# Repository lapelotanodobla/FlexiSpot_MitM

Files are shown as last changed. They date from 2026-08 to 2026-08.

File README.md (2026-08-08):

# Flexispot Desk → Home Assistant (ESPHome MITM)

ESP32 man-in-the-middle between a Flexispot standing desk's control box and its keypad, built on ESPHome. The keypad keeps working exactly as stock; Home Assistant gets a live height sensor, up/down/stop, presets, and the ability to wake the desk on its own.

**Hardware this was built against:** HS01B-1 keypad, CB38M2A-1 control box (Flexispot E5B family), generic ESP32 devkit (WROOM), 2× female RJ45 breakouts, one 4-channel BSS138-style bidirectional level shifter, one 4.7 kΩ + one 10 kΩ resistor.

## Why this exists

The excellent prior art ([LoctekMotion_IoT](https://github.com/iMicknl/LoctekMotion_IoT), [standing-desk-interceptor](https://github.com/nv1t/standing-desk-interceptor), [loctek_IOT_box](https://github.com/Dude88/loctek_IOT_box), [ha-flexispot-standing-desk](https://github.com/grssmnn/ha-flexispot-standing-desk)) was mostly built for control boxes with **two RJ45 ports**: the keypad keeps its own port, the ESP plugs into the spare one, and plain TX/RX does the trick — no man-in-the-middle needed, and the keypad problem never arises. On a **single-port** box like this one, the ESP has to share the one line with the keypad, and the passthrough recipes adapted for that case tend to hit the same wall: the ESP can control the desk, but the keypad goes dead ([LoctekMotion_IoT#146](https://github.com/iMicknl/LoctekMotion_IoT/issues/146)). By passively sniffing a factory-wired desk first (phase 1) and only then going active (phase 2), this project found the causes:

1. **The bus is 5 V logic, not 3.3 V** (UART idles at 4.6 V). An ESP32 transmitting at 3.3 V sits at/below the switching threshold of the 5 V-logic keypad and controller — commands "work" by luck, the keypad goes deaf. Everything here goes through a level shifter.
2. **The protocol is strict poll/response.** The controller polls `9B:04:11` at ~31 Hz; the keypad answers every poll with its key state. Nobody free-runs.
3. **RJ45 pin 4 ("PIN 20") is driven by the keypad** as a wake line: high = session active, controller starts polling ~140 ms after the rising edge, sleeps ~10 s after inactivity (announced by a `9B:04:13` burst).
4. On this desk the documented TX/RX naming is swapped: **pin 6 carries keypad→controller, pin 5 carries controller→keypad**.

Full protocol write-ups: [`docs/superpowers/specs/2026-08-08-phase1-findings.md`](docs/superpowers/specs/2026-08-08-phase1-findings.md). Raw + annotated captures in [`captures/`](captures/), frame decoder in [`tools/decode.py`](tools/decode.py).

## Architecture (one line cut, one line split)

The ESP emulates *only* the keypad, toward the controller. The controller→keypad line is never touched, so display data reaches the keypad with factory electrics:

```
controller ──pin 5──┬────────────────────────────► keypad   (polls, display, keepalives
                    │                                        — physically untouched)
                    └──► ESP listens (tap)

keypad ──pin 6 (keypad side)──► ESP ──pin 6 (desk side)──► controller
         (ESP consumes real key frames,   (ESP answers every poll:
          or forwards unknown frames)      real keys, or HA-injected keys)

keypad ──pin 4 (keypad side)──► ESP sense ──pin 4 (desk side)──► controller
         (divider → GPIO21)      (GPIO22 → shifter: mirrors keypad wake,
                                  ORs in ESP's own wake for HA commands)
```

## Wiring

Both RJ45 breakouts sit back-to-back as a "coupler". Six of the eight lines are bridged straight through; **only lines 6 and 4 are cut**, and line 5 gets a tap.

Pin numbering note: hold the plug clip-down, contacts toward you, pin 1 on the left. **Verify with a meter before trusting any table**: pin 8 = +5 V, pin 7 = GND on the desk side.

| RJ45 line | Coupler | Connections |
|---|---|---|
| 1 (RES) | straight | — |
| 2 (SWIM) | straight | — |
| 3 (n/c) | straight | — |
| 4 (PIN 20) | **CUT** | keypad side → 4.7k → `GPIO21` node → 10k → GND · desk side ← shifter `HV4`, `LV4` ← `GPIO22` |
| 5 (controller→keypad UART) | straight + tap | tap → shifter `HV2`, `LV2` → `GPIO17` |
| 6 (keypad→controller UART) | **CUT** | keypad side → shifter `HV1`, `LV1` → `GPIO16` · desk side ← shifter `HV3`, `LV3` ← `GPIO23` |
| 7 (GND) | straight | ESP `GND`, shifter `GND` |
| 8 (+5 V) | straight | ESP `VIN`, shifter `HV` ref |

Shifter `LV` ref ← ESP `3V3`.

**Electrical notes**

- ESP32 pins are **not 5 V tolerant** — nothing from the bus may touch a GPIO without the shifter or the divider.
- The PIN 20 *sense* is a plain resistor divider (not a shifter channel) on purpose: shifter boards pull their HV side to 5 V, which would hold a sleeping desk awake.
- Power the ESP from desk 5 V (pin 8 → VIN). **Never desk 5 V and USB at the same time** — unplug the pin-8 lead before flashing over USB. OTA needs no cable.
- All ESP-side connections live on one header row of a 30-pin devkit (GPIO16/17/21/22/23 + 3V3 + GND) — single-side soldering, and none are boot-strapping pins.

## Repo layout

| Path | What |
|---|---|
| `desk-mitm.yaml` | The active MITM node (phase 2, current) |
| `desk-sniffer.yaml` | Passive sniffer node (phase 1, known-good fallback; wiring differs — see its spec) |
| `components/desk_mitm/` | ESPHome external component: `protocol.h` (pure logic) + glue |
| `tests/test_protocol.cpp` | Host-side unit tests; every vector is a captured frame |
| `captures/` | Raw + annotated sniff sessions |
| `tools/decode.py` | Turns a capture log into an annotated timeline |
| `docs/superpowers/specs/` | Design specs and protocol findings |
| `docs/superpowers/plans/` | Implementation plans |

## Usage

```sh
# secrets.yaml (not committed): wifi_ssid + wifi_password
esphome run desk-mitm.yaml                     # first flash over USB, then OTA
esphome logs desk-mitm.yaml                    # live logs over WiFi
c++ -std=c++17 -o build/test_protocol tests/test_protocol.cpp && ./build/test_protocol
```

Home Assistant entities (via native ESPHome API): a **cover named after the device** (position slider mapped over the calibrated travel range, open/close/stop) and a **`Target Height` number** (cm — type 110, desk goes to 110.0 ± 0.1), both driven by an on-device closed-loop engine (~500 ms wake from sleep, lands within one display quantum, physical keypad presses instantly override any automated move). Plus `Height` (cm, fetched automatically at boot via a wake pulse), buttons `Nudge Up`, `Nudge Down`, `Stop`, `Preset 1/2/3`, an `Emulation Mode` config switch, and diagnostics `Keypad Active` (PIN 20 sense), `Controller Awake` (disabled by default), `Refresh Height`. The node also serves a local web UI + REST API at its IP (`web_server`).

Calibrate once: jog to the physical bottom and top, read both heights, set the `min_height`/`max_height` substitutions. Closed-loop tunables (`coast_margin`, `deadband`, `settle_ms`, …) are component config — a heavier desk coasts further; that's the knob if landings need correction taps.

**ESP8266?** Workable: the keypad-side RX moves to software serial (only one full hardware UART), `logger: baud_rate: 0` frees UART0, and drop `web_server` for RAM. The component itself is platform-independent. An ESP32 remains the recommendation.

**Emulation Mode off** (default at boot) = echo mode: the ESP replays the real keypad's frames verbatim — zero protocol logic in the loop, useful as a first bring-up step and a permanent escape hatch. Injection requires the switch on.

## Protocol cheat sheet

Frames: `9B <len> <type> <payload…> <crc_hi> <crc_lo> 9D` · 9600 8N1 · `len` counts everything after itself incl. the `9D` · CRC-16/MODBUS over `[len, type, payload]`, high byte first.

| Frame | Who | Meaning |
|---|---|---|
| `9B:04:11:7C:C3:9D` | controller | key-state poll, ~31 Hz while awake |
| `9B:06:02:<k>:00:<crc>:9D` | keypad | reply to every poll; `<k>`: 01 up · 02 down · 04/08/10 presets · 20 M |
| `9B:07:12:<3 digits>:<crc>:9D` | controller | display (7-segment bytes, bit 7 = decimal point) |
| `9B:04:15:BF:C2:9D` | controller | keepalive, ~2 Hz |
| `9B:04:13:BD:42:9D` | controller | shutdown burst right before PIN 20 falls |

Presets are fire-and-forget (one ~150 ms key burst, controller completes the move). Manual up/down move only while the key streams.

## Safety / fail-safes

All key state clears on: poll silence >500 ms, CRC failure, shutdown burst, PIN 20 fall, reboot. Injections carry hard deadlines. Only single documented key masks can ever be emitted. Worst case: unplug the ESP and re-bridge coupler lines 6 and 4 → factory desk.

**⚠ Known hazard — ASR/RST reset state.** If the ESP loses power *during a preset (autonomous) move*, the controller loses position certainty and enters its reset state: display shows `ASr`/`RST`, only downward travel works, and power cycling does **not** clear it. Recovery takes a minute and is the standard Flexispot procedure: hold Down until the desk is fully lowered and `RST` shows (~10 s extra), release; on some units then hold Up (or Up+Down) until a normal height displays. Manual moves are unaffected — the controller stops cleanly when replies vanish. Stop semantics note: reverting to idle replies never cancels a preset move; the firmware's Stop button injects a ~60 ms key tap instead, which does (verified).

## Credits

Protocol groundwork by [iMicknl/LoctekMotion_IoT](https://github.com/iMicknl/LoctekMotion_IoT) and the projects linked above; this repo's contribution is the measured 5 V finding, the poll/response + PIN 20 semantics, and the keypad-emulation architecture built on them.

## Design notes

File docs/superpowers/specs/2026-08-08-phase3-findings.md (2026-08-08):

# Phase 3 Findings — Cover + Closed-Loop Move-to-Height

**Date:** 2026-08-08. Design: `2026-08-08-phase3-cover-design.md`. All results from live verification after calibration (travel 71.0–121.0 cm).

## Accuracy (live moves, default tunables)

| Target (cm) | Landed | Error | Notes |
|---|---|---|---|
| 79.5 | 79.5 | 0.0 | cold start: wake 492 ms → done in 4 s total |
| 85.0 | 85.1 | +0.1 | awake, up |
| 75.0 | 74.9 | −0.1 | awake, down |
| 71.0 | 71.1 | +0.1 | cover close → bottom rail |
| 83.5 | 83.6 | +0.1 | mid-range |
| 121.0 | 121.0 | 0.0 | full 37.5 cm climb (~18 s), top rail |

Max error = one display quantum (0.1 cm). **Zero fine-correction taps were needed in any move** — the default `coast_margin` 0.7 cm matches this desk's real coast almost exactly; COARSE + coast alone lands inside the 0.3 cm deadband. The FINE/tap stage exists as insurance (and is sim-verified), but on this hardware it never fires.

## Behaviors verified live

- **Physical override:** keypad Down pressed ~1.8 s into an automated 31 cm descent → `physical key 02 overrides move-to-height; aborting`, instant. Human always wins.
- **Cold-start moves:** target set while desk asleep → PIN 20 wake (~490 ms to polling), move runs, desk re-sleeps on its own.
- **Cover semantics:** position slider, open (→121.0), close (→71.1), all landing on the rails; position math verified against calibration (75.0 cm ↔ 0.246 pre-calibration, correct per formula).
- **Sleep cycles between moves** are handled transparently — back-to-back commands mix awake and cold-start paths without special-casing.

## Not exercised live (sim-verified only)

Stall abort (would require blocking the desk), move timeout, tap-limit exhaustion. All covered by `tests/test_protocol.cpp` against the SimDesk model.

## Tuning outcome

Ship defaults unchanged: `coast_margin` 0.7, `deadband` 0.3, `settle_ms` 1200, `move_timeout_ms` 30000, `stall_ms` 2000, `max_taps` 5. All exposed as component config for other desks (a heavier/lighter desk will coast differently — that's the knob to turn if landings start needing taps).

## Status

Phase 3 complete. The desk is a full HA citizen: cover with position, target-height box, presets, jogs, working stop, height telemetry, wake-on-demand, boot height fetch — all through a MITM that leaves the physical keypad factory-perfect.

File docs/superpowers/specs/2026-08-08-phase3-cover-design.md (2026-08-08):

# Phase 3 — Cover Entity + Closed-Loop Move-to-Height

**Date:** 2026-08-08
**Depends on:** `2026-08-08-phase2-mitm-design.md` (hardware unchanged), `2026-08-08-phase2-findings.md` (verified primitives: injection, wake, height telemetry, tap-cancels-move).

## Goal

A real Home Assistant `cover` entity (open/close/stop/position slider) and a `Target Height` (cm) number entity, both driven by one on-device closed-loop `move_to(cm)` engine. No hardware changes.

## Measured constants the design builds on (from captures/findings)

- Travel speed ≈ 2.2 cm/s during autonomous and held-key moves.
- A ~2-poll (≈60 ms) key tap moves ≈ 0.1 cm and cancels any autonomous move.
- Height frames stream continuously while moving; display resolution 0.1 cm.
- Desk coasts briefly after key release (sub-centimeter at manual speeds).
- Wake-from-asleep to first poll ≈ 500 ms via PIN 20 drive.

## MoveController (pure logic, `protocol.h`, host-tested)

State machine: `IDLE → (wake handled by glue) → COARSE → SETTLE → FINE → SETTLE → … → IDLE`.

- `move_to(target, now)`: validates target against `[min_height, max_height]`, computes direction, enters COARSE.
- **COARSE**: output the direction key continuously; when `|target − current| ≤ coast_margin` (default **0.7 cm**), release → SETTLE.
- **SETTLE**: output idle for `settle_ms` (default **1200 ms**) so coast finishes and the display catches up.
- **FINE**: if `|error| ≤ deadband` (default **0.3 cm**) → done (IDLE). Else emit one `tap_polls` (default 2) tap toward the target, → SETTLE. Max `max_taps` (default **5**) fine taps per move; exceeding it ends the move with a logged warning (good enough beats hunting).
- Tick interface: `uint8_t update(float current_height, uint32_t now_ms)` returns the key mask the glue should inject this instant; MoveController never touches hardware.

### Abort rules (all → IDLE, idle output, logged reason)

1. **Physical override**: glue reports any real-keypad key ≥ 1 frame → abort immediately. Human wins, always.
2. **Fail-safe events**: poll silence, `type 13` burst, PIN 20 fall, reboot (glue already clears key state; it also aborts the controller).
3. **Move timeout**: `move_timeout_ms` (default **30 s**) wall-clock cap.
4. **Stall**: height unchanged for `stall_ms` (default **2 s**) while COARSE is commanding motion — the desk's own anti-collision has tripped or something's wrong; do not fight it.

All constants are YAML substitutions with the defaults above.

## ESPHome entities

- **`cover` platform `desk_mitm`** (new `cover.py` + `DeskCover : cover::Cover`): traits position + stop. `position = (height − min_height) / (max_height − min_height)`, published on height change. `open` → `move_to(max_height)`, `close` → `move_to(min_height)`, `stop` → abort + existing stop-tap, `set_position(p)` → `move_to(min + p·(max−min))`. Device icon `mdi:desk`.
- **`number` platform `desk_mitm`** ("Target Height", cm, min/max from the same substitutions, step 0.1): `set` → `move_to(value)`. State reflects the last requested target.
- Existing sensor/buttons/switch unchanged. `move_to` while asleep rides the existing PIN 20 wake path (glue defers engine start until polling begins; existing 2 s wake timeout aborts the move if the controller never wakes).

## Calibration (bench step, part of the plan)

Jog to physical bottom and top with the keypad, read both heights in HA, set `min_height` / `max_height` substitutions. Until calibrated the YAML ships placeholder values 60.0 / 121.0 marked loudly as UNCALIBRATED.

## Testing

Host-side, extending `tests/test_protocol.cpp`: a `SimDesk` model (2.2 cm/s ramp while a key mask is applied, 0.4 cm coast after release, 0.1 cm quantization) driven against MoveController. Cases: long up move lands within deadband; long down move; early-release happens `coast_margin` before target; fine taps converge; tap cap respected; physical-override abort; stall abort; timeout abort; target clamping. The glue layer stays thin (entity plumbing + feeding `update()`), consistent with Phases 1–2.

## Non-goals

Preset programming from HA; speed control (hardware has none); ESP8266 build target (README gets a compatibility note only: 1 hW RX → software serial for keypad side, `logger baud 0`, drop `web_server`).

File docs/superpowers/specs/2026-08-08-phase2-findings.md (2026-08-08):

# Phase 2 Findings — Active MITM Verification

**Date:** 2026-08-08. Hardware per `2026-08-08-phase2-mitm-design.md` (single-cut keypad emulation, PIN 20 split). All results from live bench verification on the HS01B-1 / CB38M2A-1 desk.

## Verification ladder results

1. **Echo build — PASS.** Keypad fully functional through the ESP (display, jogs, presets). This confirms the core Phase 1 thesis: prior "keypad goes deaf" failures were 3.3 V transmit levels; at 5 V through the shifter the controller accepts ESP-relayed frames indistinguishably from the real keypad.
2. **Emulation build — PASS.** Keypad behavior indistinguishable from stock with the ESP synthesizing every poll reply from parsed key state. Height sensor tracks the display frames live.
3. **Injection — PASS.** HA/REST preset buttons execute full moves (verified to stored heights, e.g. preset 3 → exactly 75.0 cm); up/down jogs nudge as expected.
4. **ESP-initiated wake — PASS, deterministic.** Driving desk-side PIN 20 wakes the controller reliably: measured 493 ms, 508 ms, 524 ms, ~491 ms from drive to first poll across runs. **No polling was ever observed without the PIN 20 drive** — the UART-only wake hypothesis from older projects is dead on this hardware; the PIN 20 split is required for autonomous control.
5. **Abuse pass — one real discovery** (see hazard below). Not explicitly exercised: keypad unplug mid-manual-move (fail-safe designed: 500 ms poll-silence clears keys), OTA mid-move.

## Stop semantics (settled)

- Reverting to idle replies does **not** cancel a controller-autonomous (preset) move — the controller finishes on its own, exactly as the fire-and-forget model predicted.
- **Any brief up/down key press cancels an in-flight preset move** (verified physically and via injection).
- `stop()` therefore injects a ~60 ms (2-poll) up-tap, gated on "height changed within 500 ms" so Stop on an idle desk remains a true no-op. Verified: preset 1 launched from 77.2 cm, Stop pressed ≈1 s in, desk halted at 78.3 cm.

## Bugs found on hardware (both fixed)

1. **Watchdog time-underflow flap:** `loop()` captured `millis()` before draining UARTs while frame handlers stamped `last_poll_ms_` fresher; the unsigned subtraction wrapped and fired a false 500 ms poll timeout every cycle. Symptom: polling state flapping ~10×/s. Echo mode masked it (echo replies bypass key state). Fix: watchdog timestamp taken after the drain.
2. **Boot height fetch race:** the on-boot no-injection wake can race the controller's own sleep transition and produce nothing. Fix: bounded retry (3 attempts, 30 s apart, only until a height is ever decoded) plus a manual `Refresh Height` button.

## ⚠ Known hazard: ASR/RST reset state

**Cutting ESP power during a controller-autonomous (preset) move puts the desk into the ASR ("ASr"/"A5T"/"RST" on the display) reset state**: the controller loses position certainty when its keypad (the ESP) vanishes mid-move. In this state only downward travel works and power cycling does not clear it. Recovery (~1 minute, standard Flexispot procedure): hold Down until fully lowered, keep holding ~10 s until `RST` shows, release; if needed hold Up (or Up+Down on some units) until a normal height displays. Manual moves do not trigger this — the controller stops cleanly on reply silence. Documented in the README.

## Extra observations

- The keypad wakes itself when the controller starts transmitting on (intact) pin 5 — so HA-initiated moves light up the keypad display for free.
- Wake latency consistency (±20 ms around 500 ms) suggests a fixed controller boot sequence, useful as a health signal.
- Cold-wake injection sessions end with the same `type 13` shutdown burst + PIN 20 fall as keypad sessions; the controller makes no distinction between a real keypad and the emulation.

## Status

Phase 2 complete: keypad fully functional, HA control (height / jogs / presets / working Stop / wake-on-demand / boot height) verified end to end. Phase 3 candidates: closed-loop move-to-height, cover entity, hold-to-jog, preset programming from HA.

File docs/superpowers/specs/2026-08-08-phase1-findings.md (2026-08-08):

# Phase 1 Findings — HS01B-1 / CB38M2A-1 Protocol Sniff

**Source:** `captures/2026-08-08-session1.log` (annotated: `.md` sibling, decoder: `tools/decode.py`), captured with the passive Y-tap node (`desk-sniffer.yaml`). All frames CRC-verified 9600 8N1, format `9b <len> <type> <payload…> <crc16> 9d`.

## Physical-layer corrections vs the reference docs

- **5 V logic**, not 3.3 V (idle high 4.6 V). Any device transmitting to the controller or keypad at 3.3 V sits at/below the 5 V-logic V_IH — this is the most likely root cause of the "ESP works but keypad dies" failure mode in prior passthrough builds (iMicknl/LoctekMotion_IoT#146).
- **Direction naming is reversed** vs the iMicknl HS01B-1 table on this desk: RJ45 **pin 6 carries keypad→controller**, **pin 5 carries controller→keypad**.
- The keypad **tri-states its TX when asleep** (~1 V float); controller line idles high always.

## Protocol structure: poll/response, not free-running

Frame counts over the session: controller `type 11` = 2486, keypad `type 02` = 2486 — **exactly 1:1, with the keypad's reply ~6 ms after each poll**.

While awake (~31 Hz):

| Frame | Direction | Meaning |
|---|---|---|
| `9B:04:11:7C:C3:9D` | controller→keypad | Key-state poll, ~31 Hz |
| `9B:06:02:<k1>:<k2>:<crc>:9D` | keypad→controller | Key-state reply to every poll |
| `9B:07:12:07:<d2>:<d3>:<crc>:9D` | controller→keypad | Display update (7-segment encoding, bit7 = decimal point), sent on change + periodic refresh |
| `9B:04:15:BF:C2:9D` | controller→keypad | Keepalive, ~2 Hz while awake |
| `9B:04:13:BD:42:9D` | controller→keypad | Shutdown announcement — burst of ~8 in the ~100 ms before PIN 20 falls |

## (a) Keypad command frames — confirmed, full button map

The keypad answers every poll with `9B:06:02:<keys>:00:<crc>:9D`. `<keys>` is a bitmask; observed values match the LoctekMotion command table:

| Button | Payload | Observed |
|---|---|---|
| none | `00:00` | continuous idle |
| Up | `01:00` | tap = 4 frames (~100 ms), hold = continuous |
| Down | `02:00` | same pattern |
| Preset 1 | `04:00` | single ~5-frame burst, desk then moves autonomously |
| Preset 2 | `08:00` | same |
| Preset 3 | `10:00` | same |
| M | `20:00` | display switches to `S-` programming prompt for ~4 s, then reverts |

Key facts: a **preset tap is fire-and-forget** — the desk completes the whole move while the keypad streams `00:00`. Manual up/down moves only while the key code streams; release stops the desk.

## (b) PIN 20 — answered

- **The keypad drives PIN 20.** Rising edge comes first; controller UART starts polling ~140 ms later; first clean frame ~350 ms after the edge.
- Stays high while awake; drops after **~10 s of inactivity** (button presses and motion reset the timer).
- The controller announces the impending sleep with the `type 13` burst, *then* PIN 20 falls, then both transmitters die mid-stream (trailing garbage bytes `9B:FF`, partial frames are normal at power-down and must be discarded).
- Wake transients: the keypad's first ~2 bytes after the rising edge (`00`, `FE`) are garbage — ignore bytes for ~300 ms after the edge.

## (c) Frames absent from the reference docs

`type 11` (poll), `type 13` (shutdown), `type 15` (keepalive) are not in the LoctekMotion tables. Issue #146's mystery frame `9B:05:02:00:A1:60:9D` (len 05) did not appear here — likely a variant firmware's idle reply.

## (d) Phase 2 (active MITM) requirements

1. **Level shift everything** — 5 V toward desk and keypad. 3.3 V TX is not reliably heard.
2. **Split PIN 20**: sense the keypad side (divider→GPIO), drive the desk side (shifter channel). Mirror keypad→desk by default; OR-in ESP's own wake when injecting.
3. **To inject a command with the keypad asleep**: drive desk-side PIN 20 high, wait ≥350 ms for the controller to start polling, then answer polls with the command payload for ~4-5 polls (~150 ms), then stream `00:00` idle replies. Presets are fire-and-forget after that; the move completes on its own. Keep PIN 20 high at least until the move ends (height sensor goes quiet).
4. **The controller is the poll master.** A passthrough MITM must forward polls promptly; the observed poll→reply turnaround is ~6 ms, so per-byte forwarding latency well under that is required. Frame-level store-and-forward at ~1 ms/byte UART speed fits comfortably.
5. **Height telemetry is free**: decode `type 12` display frames — payload is frame bytes 3–5 (after `9B <len> 12`), 7-segment encoded, bit7 = decimal point; 3-digit values ≥100 drop the dot. Decoder validated against session 1: continuous cm readings 75.0–121.0 with no gaps (session presets: P1=121.0, P2≈77.2, P3=75.0). Non-numeric glyphs appear only in the M-mode `S-` prompt.
6. **Hygiene**: discard partial frames after `type 13`/PIN 20 fall; ignore first ~300 ms of keypad bytes after wake.

## Exit criteria

Questions (a) and (b) from the design spec are answered from captures — Phase 1 complete. Not yet captured: preset *programming* exchange (session step 11 skipped); can be added to a later session if Phase 2 needs it.

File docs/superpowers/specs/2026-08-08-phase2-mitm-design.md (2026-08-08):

# Phase 2 — Active MITM via Keypad Emulation (single-cut)

**Date:** 2026-08-08 (rev 2 after external review — see "Review outcomes" at bottom)
**Depends on:** `2026-08-08-desk-sniffer-design.md` (Phase 1 hardware), `2026-08-08-phase1-findings.md` (protocol ground truth).

## Goal

The ESP32 intercepts only the keypad→controller direction, keeps the keypad fully functional, and adds minimal HA control: height sensor + buttons (up, down, stop, preset 1/2/3), with deterministic ESP-initiated wake.

## Architecture: emulate the keypad only

**Controller→keypad (pin 5) stays physically intact** — display frames, polls, keepalives and shutdown reach the keypad with original electrics and timing; the ESP taps it read-only (as in Phase 1). Only **keypad→controller (pin 6) is cut**: the ESP receives the real keypad's replies on the keypad-side segment and is the sole talker on the desk-side segment.

- The ESP hears every `9B:04:11` poll on the pin-5 tap and answers on desk-side pin 6 immediately with `9B:06:02:<keys>:00:<crc>:9D` from local state.
- `<keys>` = injected command if an injection is active, **else** latest real-keypad key state. Injection *replaces* (never ORs with) physical keys; opposing/undocumented combinations are never emitted.
- The real keypad still hears polls directly (pin 5 intact) and replies on its own schedule; the ESP consumes those replies to update `real_keypad_keys`.
- Any keypad frame that is **not** `type 02` is forwarded to the controller verbatim (covers preset-programming and unknown exchanges).

**PIN 20 (pin 4) is also cut**: keypad-side segment keeps the existing 4.7k/10k divider → GPIO34 (sense); desk-side segment is driven at 5 V via shifter ch 4. Firmware mirrors keypad→desk and ORs in its own wake request when injecting. This makes ESP-initiated wake deterministic instead of hoping the controller wakes from UART frames alone. (The UART-only wake question can still be answered experimentally from logs, but nothing depends on it.)

### Fail-safe key-state rules

- All key state (injected and mirrored) **clears** on: parser/CRC error on either bus, no controller poll for 500 ms, `type 13` shutdown burst, PIN 20 fall, reboot, or OTA.
- Injections carry a hard deadline (~150 ms for command bursts) — expiry clears them regardless of poll arrival; a stuck injection cannot outlive its window.
- Ignore keypad bytes for 300 ms after keypad-side PIN 20 rises (wake transients); discard partial frames after shutdown.
- Reply exactly once per received poll — never on a self-generated schedule (log timestamps from Phase 1 are batched and unsuitable for deriving a clock; the poll itself is the clock).

### Injection semantics

- **Preset 1/2/3** (`04`/`08`/`10`): command payload in poll replies for ~150 ms (4–5 polls observed from the real keypad; duration-bounded, not count-exact), then idle. Move is fire-and-forget by the controller.
- **Up / Down** (`01`/`02`): stream for ~300 ms per HA button press (coarse jog; closed-loop control is Phase 3).
- **Stop**: clear injection immediately — verified to stop *manual* motion. Whether it cancels a preset move is unknown; tested on the bench in verification step 3 and the entity renamed/documented accordingly if not.
- If the controller is asleep (no polls), an injection first raises desk-side PIN 20, waits for polling to start (~350 ms observed keypad-wake latency; timeout 2 s), then proceeds. PIN 20 held until the move completes (height frames go quiet) plus 1 s.

## Hardware delta from Phase 1

Cut RJ45 lines **6 and 4** inside the coupler; lines 1, 2, 3, 5, 7, 8 stay straight through.

| Segment | Via | ESP pin |
|---|---|---|
| Keypad-side pin 6 (keypad TX) → ESP | shifter ch 1 (existing) | GPIO16 (uart_keypad RX-only) |
| Desk-side pin 5 tap (controller TX) → ESP | shifter ch 2 (existing) | GPIO17 (uart_desk RX) |
| ESP → desk-side pin 6 (controller RX) | shifter ch 3 (new) | GPIO26 (uart_desk TX) |
| ESP → desk-side pin 4 (PIN 20 drive) | shifter ch 4 (new) | GPIO27 (output) |
| Keypad-side pin 4 → ESP | 4.7k/10k divider (existing) | GPIO34 (sense) |

All four channels of the single BSS138 board are now used; no second board needed. BSS138 + 10k pullup rise time (~2–5 µs) is ~2% of a 104 µs bit at 9600 baud — adequate; verification step 1 confirms empirically before anything depends on it.

## Firmware structure

- `components/desk_mitm/` — ESPHome external component (C++): shared frame parser (`9B` → len → payload → CRC-16/MODBUS → `9D`), key-state model with the fail-safe rules above, injection queue, height decoder (7-segment, payload bytes 3–5, validated against session 1), PIN 20 mirror/wake logic.
- Entities: `height` sensor (cm), `keypad_active` (GPIO34), `controller_polling` (diagnostic), buttons up/down/stop/preset 1–3.
- `desk-mitm.yaml` — new node config (same device name/IP). `desk-sniffer.yaml` stays untouched as the known-good fallback build.
- **Echo mode** (boolean): ESP re-emits the real keypad's `type 02` replies verbatim instead of synthesizing from state — the minimal-logic first build and a permanent escape hatch.

## Verification ladder (each step gates the next)

1. **Echo build**: physical keypad fully functional through the ESP (buttons move desk, display live) → proves the 5 V TX path, the cut wiring, and PIN 20 mirroring with minimal firmware in the loop.
2. **Emulation build**: keypad still factory-perfect; height sensor live in HA while moving with the keypad; kill-switch checks (yank keypad mid-hold → desk stops within 500 ms via poll-timeout rule).
3. **Injection, keypad awake**: HA preset button moves desk; stop behavior during manual jog and during a preset move recorded.
4. **ESP wake, keypad asleep**: HA preset from cold — PIN 20 drive brings controller up, injection completes. Also log whether polling ever starts *without* the PIN 20 drive (settles the UART-only wake question for the record).
5. **Abuse pass**: reboot ESP mid-move, OTA mid-move, simultaneous HA + physical input (physical wins after injection window), sleep-boundary injections.

## Risks

- Controller may validate reply timing/content more strictly than observed → reply-on-poll from RAM, echo-mode fallback.
- Keypad may misbehave when its TX has no controller listening (it talks only to the ESP now) → it can't tell the difference electrically; RX-side unchanged.
- Worst case recovery: unplug ESP, re-bridge coupler lines 6 and 4 → factory desk (two jumpers, documented here).

## Non-goals (deferred to Phase 3)

Closed-loop move-to-height, cover/position entity, hold-to-jog from HA, preset programming from HA.

## Review outcomes (Codex second opinion, 2026-08-08)

Accepted: single-cut architecture (pin 5 intact); PIN 20 split now instead of the UART-wake experiment; fail-safe key-state clearing; injection replaces rather than ORs physical keys; duration-bounded injection; poll-as-clock (no schedule derived from batched log timestamps); stop-semantics caveat; height decoder byte-indexing bug fixed and re-validated (`tools/decode.py`, payload bytes 3–5).
Rejected: replacing BSS138 with a dedicated buffer (rise time is 2% of bit period at 9600; empirically gated in step 1); removing the wake observation entirely (kept as free logging, nothing depends on it).

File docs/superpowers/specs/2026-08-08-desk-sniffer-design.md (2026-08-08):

# Flexispot Desk — ESPHome Sniffer/MITM Design

**Date:** 2026-08-08
**Hardware:** Flexispot desk with HS01B-1 keypad / CB38M2A-1 control box, generic ESP32 devkit, 2× female RJ45 breakouts.
**Context:** Prior attempts (like [iMicknl/LoctekMotion_IoT#146](https://github.com/iMicknl/LoctekMotion_IoT/issues/146)) get ESP control of the desk working but the keypad goes dead, with only a repeating `9B:05:02:00:A1:60:9D` frame visible and no button-press frames. Root cause unknown; suspected to involve RJ45 pin 4 ("PIN 20", the screen-activation line). We start from scratch and capture ground truth before building control.

## Goals

1. **Phase 1 (this spec):** a purely passive tap that logs all traffic in both directions plus the PIN 20 line, while desk and keypad remain in a factory-original circuit.
2. Use those captures to answer: what does a real HS01B-1 keypad send when buttons are pressed, and how does PIN 20 behave?
3. **Phase 2 (later, informed by Phase 1):** active MITM passthrough with command injection.
4. **Phase 3 (later):** full HA integration (height sensor, presets, up/down) with a working keypad.

## Non-goals (Phase 1)

- No desk control from the ESP. No TX pins connected. No HA control entities.
- No decoding logic on the node itself — raw hex logging only; analysis happens on the captured logs.

## Reference protocol (from LoctekMotion_IoT docs)

- UART 9600 baud, 8N1.
- Frames: `9b <len> <type> <payload…> <crc16-lo> <crc16-hi> 9d`.
- Controller→keypad: height display frames. Keypad→controller: command frames (e.g. wake `9b 06 02 00 00 6c a1 9d`).
- Control box accepts commands only while the "screen is active"; PIN 20 HIGH for ~1 s activates it.
- HS01B-1 RJ45 pinout: 8=+5V, 7=GND, 6=desk-TX, 5=desk-RX (keypad-TX), 4=PIN 20, 3/2/1=NC/SWIM/RES.

## Topology: Y-tap (passive)

All 8 lines run straight through between the two RJ45 jacks (desk cable in one, keypad in the other — electrically a coupler). Three signal lines and power additionally branch to the ESP:

```
desk RJ45 ═══════════ 8 straight wires ═══════════ keypad RJ45
                │           │          │
              pin 6       pin 5      pin 4
                │           │          │
             GPIO16      GPIO17     GPIO34      (+ pin 8→VIN, pin 7→GND)
                └────── ESP32 only listens ──────┘
```

| RJ45 line | ESP pin | Role |
|---|---|---|
| 8 (+5V) | VIN | Powers ESP from desk |
| 7 (GND) | GND | Common ground |
| 6 (desk-TX) | GPIO16 (via shifter ch. 1) | UART1 RX — controller→keypad traffic |
| 5 (keypad-TX) | GPIO17 (via shifter ch. 2) | UART2 RX — keypad→controller traffic |
| 4 (PIN 20) | GPIO34 (via 4.7k/10k divider) | Digital input (input-only pin), edge logging |

**Measured levels (2026-08-08, keypad direct to desk, vs pin 7):**

| Line | Keypad asleep | Keypad active |
|---|---|---|
| 4 (PIN 20) | 0 V | 4.1 V |
| 5 (keypad-TX) | 1 V (undriven/float) | 3.7 V |
| 6 (desk-TX) | 4.6 V (UART idle high) | 3.5 V (avg while transmitting) |

Conclusion: **5 V logic**, and PIN 20 is at 4.1 V while the keypad is awake. This is also the leading hypothesis for why past passthrough builds killed the keypad: the ESP re-transmitted desk frames at 3.3 V, below reliable V_IH for 5 V logic, so the keypad never heard them (and 3.3 V on PIN 20 may likewise not register as "high").

**Level shifting (ESP32 GPIOs are not 5 V tolerant, and Phase 2 must transmit at 5 V):**

- **Pins 6 and 5 (both UARTs): 4-channel BSS138-style bidirectional shifter board** from the start — correct RX levels now, correct 5 V TX in Phase 2 with no rewiring. RJ45 pin 8 → HV ref, ESP 3V3 → LV ref, common GND. Channel 1: pin 6 ↔ GPIO16; channel 2: pin 5 ↔ GPIO17. Do not use TXS0108-type auto-direction chips (unreliable with bus pullups/long cables at these speeds).
- **Pin 4 (PIN 20): plain resistor divider** — 4.7k from line to GPIO34, 10k from GPIO34 to GND (5 V→3.4 V; V_IH ≈ 2.5 V, abs max 3.6 V). Deliberately *not* on the shifter in Phase 1: the board's 10k HV pull-ups could pull a passively-low PIN 20 up to 5 V and hold the desk awake, contaminating the capture. If Phase 2 needs to drive PIN 20, that gets a dedicated 5 V driver (spare shifter channel or transistor) informed by the captures.

## ESPHome node (`desk-sniffer.yaml`)

- Board: generic `esp32dev`. WiFi from existing `secrets.yaml`; device currently at 192.168.40.65, known to HA as "Flexispot Desk". Keep `api:` + `ota:` so HA connectivity and OTA updates work.
- Two RX-only `uart:` buses at 9600 8N1 with `debug:` enabled, `after: delimiter: 0x9D`, hex dump `sequence`, direction-labeled `DESK>` (GPIO16 bus) and `KEYPAD>` (GPIO17 bus).
- `binary_sensor` (GPIO platform) on GPIO34 for PIN 20, logging state changes; exposed to HA for convenience.
- Logger at `DEBUG` level over WiFi (`esphome logs`); USB serial only needed for the first flash.

## Verification plan

1. Flash over USB → node joins WiFi → `esphome logs` streams over the network.
2. Keypad sanity in Y-tap circuit: display shows height, buttons move desk. If not, debug wiring/crimps before anything else — the circuit is electrically original, so failure here is physical.
3. Capture a labeled session into a log file committed to this repo (`captures/`): idle baseline, each button press (up, down, presets 1–3, M), a full preset move, preset programming — noting PIN 20 edges throughout.
4. Analysis answers, explicitly written up: (a) does the keypad emit `9b 06 02 …` command frames, and which; (b) PIN 20 behavior at rest / on wake / during presses; (c) any frames not in the LoctekMotion docs.

Exit criterion for Phase 1: questions (a) and (b) answered from captures. That data drives the Phase 2 design (how the MITM must drive/relay PIN 20 so the keypad stays alive).

## Risks

- **Voltage:** measured 5 V logic; mitigated by the dividers above.
- **UART invert/idle level:** if a bus shows garbage, first suspects are swapped pins 5/6 or inverted logic (`invert: true` on the UART pin is the test).
- **GPIO34 has no internal pull:** if PIN 20 floats when idle, readings may bounce; acceptable for logging (we care about driven states), can add external pulldown if noisy.
- **Powering from desk during flashing:** never USB and desk 5 V simultaneously unless the devkit's diode handles it; unplug RJ45 power lead when flashing over USB.

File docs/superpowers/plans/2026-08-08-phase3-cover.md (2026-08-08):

# Phase 3 Cover + Move-to-Height Implementation Plan

> **For agentic workers:** REQUIRED SUB-SKILL: Use superpowers:subagent-driven-development (recommended) or superpowers:executing-plans to implement this plan task-by-task. Steps use checkbox (`- [ ]`) syntax for tracking.

**Goal:** HA `cover` entity (open/close/stop/position) and `Target Height` number, driven by a host-tested closed-loop `MoveController` in the existing `desk_mitm` component.

**Architecture:** Per `docs/superpowers/specs/2026-08-08-phase3-cover-design.md`. `MoveController` is pure logic in `protocol.h`, ticked by the glue loop; it outputs a key mask, never touches hardware. Cover/number are thin ESPHome platforms on the component. No hardware changes.

**Tech Stack:** Existing repo conventions — pure C++ TDD via `tests/test_protocol.cpp` + `c++ -std=c++17`, ESPHome external component platforms (`cover.py`, `number.py`).

**Key constants (from findings):** travel ≈2.2 cm/s, 2-poll tap ≈0.1 cm, coast ≈0.4 cm, display step 0.1 cm.

---

### Task 1: MoveController happy path (TDD with SimDesk)

**Files:**
- Modify: `components/desk_mitm/protocol.h`
- Modify: `tests/test_protocol.cpp`

- [ ] **Step 1: Add SimDesk + happy-path tests** (append to `tests/test_protocol.cpp`, call new tests from `main`)

```cpp
// Simulated desk: 2.2 cm/s while a key is held, 0.4 cm coast after release,
// display quantized to 0.1 cm. Matches measured constants in the findings docs.
struct SimDesk {
  float h;
  float coast_left{0};
  int dir{0};
  void step(uint8_t mask, uint32_t dt_ms) {
    const float v = 2.2f * dt_ms / 1000.0f;
    if (mask == 0x01) { h += v; dir = 1; coast_left = 0.4f; }
    else if (mask == 0x02) { h -= v; dir = -1; coast_left = 0.4f; }
    else if (coast_left > 0) {
      float c = v < coast_left ? v : coast_left;
      h += dir * c;
      coast_left -= c;
    }
  }
  float display() const { return roundf(h * 10) / 10; }
};

// Drive controller against sim until it goes idle or 60 simulated seconds pass.
static void run_sim(MoveController &mc, SimDesk &sim, uint32_t &now) {
  const uint32_t deadline = now + 60000;
  while (mc.active() && now < deadline) {
    uint8_t mask = mc.update(sim.display(), now);
    sim.step(mask, 10);
    now += 10;
  }
}

static void test_move_controller_happy() {
  MoveConfig cfg;  // defaults from the spec
  {  // long up move lands within deadband
    MoveController mc(cfg);
    SimDesk sim{75.0f};
    uint32_t now = 1000;
    assert(mc.move_to(110.0f, sim.display(), now));
    run_sim(mc, sim, now);
    assert(!mc.active());
    assert(mc.end_reason() == MoveEnd::DONE);
    assert(std::fabs(sim.display() - 110.0f) <= cfg.deadband + 0.001f);
  }
  {  // long down move
    MoveController mc(cfg);
    SimDesk sim{110.0f};
    uint32_t now = 1000;
    assert(mc.move_to(75.0f, sim.display(), now));
    run_sim(mc, sim, now);
    assert(mc.end_reason() == MoveEnd::DONE);
    assert(std::fabs(sim.display() - 75.0f) <= cfg.deadband + 0.001f);
  }
  {  // early release: key must drop out BEFORE the display reaches the target
    MoveController mc(cfg);
    SimDesk sim{80.0f};
    uint32_t now = 1000;
    mc.move_to(90.0f, sim.display(), now);
    float last_commanded_h = NAN;
    while (mc.active() && now < 61000) {
      uint8_t mask = mc.update(sim.display(), now);
      if (mask != 0) last_commanded_h = sim.display();
      sim.step(mask, 10);
      now += 10;
    }
    assert(mc.end_reason() == MoveEnd::DONE);
    assert(last_commanded_h < 90.0f);  // released below target, coast covered the rest
  }
  {  // target outside range is clamped to the rail
    MoveConfig c2;
    c2.min_height = 60.0f;
    c2.max_height = 121.0f;
    MoveController mc(c2);
    SimDesk sim{119.0f};
    uint32_t now = 1000;
    assert(mc.move_to(300.0f, sim.display(), now));
    run_sim(mc, sim, now);
    assert(std::fabs(sim.display() - 121.0f) <= c2.deadband + 0.001f);
  }
  {  // NaN target rejected outright
    MoveController mc(cfg);
    assert(!mc.move_to(NAN, 75.0f, 1000));
    assert(!mc.active());
  }
}
```

- [ ] **Step 2: Run to verify failure**

Run: `c++ -std=c++17 -o build/test_protocol tests/test_protocol.cpp && ./build/test_protocol`
Expected: compile error — `MoveConfig`/`MoveController`/`MoveEnd` not defined.

- [ ] **Step 3: Implement in `protocol.h`** (before the closing `}  // namespace desk_mitm`)

```cpp
struct MoveConfig {
  float min_height{60.0f}, max_height{121.0f};
  float coast_margin{0.7f}, deadband{0.3f};
  uint32_t settle_ms{1200}, move_timeout_ms{30000}, stall_ms{2000}, tap_ms{60};
  uint8_t max_taps{5};
};

enum class MoveEnd : uint8_t { NONE, DONE, TAP_LIMIT, TIMEOUT, STALL, ABORTED };

// Closed-loop move engine. Pure logic: tick update() with the latest decoded
// height; it returns the key mask to emit right now (0 = idle). Never touches
// hardware; the glue owns wake, injection and abort triggers.
class MoveController {
 public:
  explicit MoveController(const MoveConfig &cfg) : cfg_(cfg) {}
  void set_config(const MoveConfig &cfg) { cfg_ = cfg; }

  // Starts a move. Target is clamped to [min_height, max_height]; NaN rejected.
  // `current` may be NAN (height not yet known) — COARSE waits for frames.
  bool move_to(float target, float current, uint32_t now) {
    if (std::isnan(target)) return false;
    if (target < cfg_.min_height) target = cfg_.min_height;
    if (target > cfg_.max_height) target = cfg_.max_height;
    target_ = target;
    start_ms_ = now;
    last_h_ = current;
    last_h_change_ = now;
    taps_ = 0;
    end_ = MoveEnd::NONE;
    state_ = State::COARSE;
    return true;
  }

  void abort() {
    if (state_ != State::IDLE) end_ = MoveEnd::ABORTED;
    state_ = State::IDLE;
  }

  bool active() const { return state_ != State::IDLE; }
  MoveEnd end_reason() const { return end_; }
  float target() const { return target_; }
  // Direction of the current move: +1 up, -1 down, 0 idle. For cover operation state.
  int direction(float current) const {
    if (state_ == State::IDLE || std::isnan(current)) return 0;
    return target_ > current ? 1 : -1;
  }

  uint8_t update(float h, uint32_t now) {
    if (state_ == State::IDLE) return 0;
    if (now - start_ms_ > cfg_.move_timeout_ms) return end_with_(MoveEnd::TIMEOUT);
    switch (state_) {
      case State::COARSE: {
        if (std::isnan(h)) {
          // Height unknown (e.g. just woke): hold still, wait for frames.
          // The stall guard below uses last_h_change_, armed at move start.
          if (now - last_h_change_ > cfg_.stall_ms) return end_with_(MoveEnd::STALL);
          return 0;
        }
        if (std::isnan(last_h_) || h != last_h_) { last_h_ = h; last_h_change_ = now; }
        float err = target_ - h;
        if (std::fabs(err) <= cfg_.coast_margin) {
          state_ = State::SETTLE;
          settle_until_ = now + cfg_.settle_ms;
          return 0;
        }
        // Stall only matters while we are commanding motion and it isn't happening.
        if (now - last_h_change_ > cfg_.stall_ms) return end_with_(MoveEnd::STALL);
        return err > 0 ? 0x01 : 0x02;
      }
      case State::SETTLE:
        if (now < settle_until_) return 0;
        state_ = State::FINE;
        [[fallthrough]];
      case State::FINE: {
        if (std::isnan(h)) return end_with_(MoveEnd::STALL);
        float err = target_ - h;
        if (std::fabs(err) <= cfg_.deadband) return end_with_(MoveEnd::DONE);
        if (taps_ >= cfg_.max_taps) return end_with_(MoveEnd::TAP_LIMIT);
        taps_++;
        tap_key_ = err > 0 ? 0x01 : 0x02;
        tap_until_ = now + cfg_.tap_ms;
        state_ = State::TAP;
        return tap_key_;
      }
      case State::TAP:
        if (now < tap_until_) return tap_key_;
        state_ = State::SETTLE;
        settle_until_ = now + cfg_.settle_ms;
        return 0;
      case State::IDLE:
        break;
    }
    return 0;
  }

 private:
  uint8_t end_with_(MoveEnd e) {
    end_ = e;
    state_ = State::IDLE;
    return 0;
  }

  enum class State : uint8_t { IDLE, COARSE, SETTLE, FINE, TAP } state_{State::IDLE};
  MoveConfig cfg_;
  float target_{NAN}, last_h_{NAN};
  uint32_t start_ms_{0}, last_h_change_{0}, settle_until_{0}, tap_until_{0};
  uint8_t taps_{0}, tap_key_{0};
  MoveEnd end_{MoveEnd::NONE};
};
```

- [ ] **Step 4: Run tests** — `c++ -std=c++17 -o build/test_protocol tests/test_protocol.cpp && ./build/test_protocol` → `all tests passed`
- [ ] **Step 5: Commit** — `git add components tests && git commit -m "feat: MoveController closed-loop engine with simulated-desk tests"`

---

### Task 2: MoveController failure paths (TDD)

**Files:**
- Modify: `tests/test_protocol.cpp`

- [ ] **Step 1: Add failure-path tests** (call from `main`)

```cpp
static void test_move_controller_failures() {
  MoveConfig cfg;
  {  // abort mid-move: goes idle, outputs 0
    MoveController mc(cfg);
    SimDesk sim{75.0f};
    uint32_t now = 1000;
    mc.move_to(110.0f, sim.display(), now);
    (void) mc.update(sim.display(), now);
    mc.abort();
    assert(!mc.active());
    assert(mc.end_reason() == MoveEnd::ABORTED);
    assert(mc.update(sim.display(), now + 10) == 0);
  }
  {  // stall: height frozen while commanding motion
    MoveController mc(cfg);
    uint32_t now = 1000;
    mc.move_to(110.0f, 75.0f, now);
    while (mc.active() && now < 20000) {
      (void) mc.update(75.0f, now);  // desk never moves
      now += 10;
    }
    assert(mc.end_reason() == MoveEnd::STALL);
    assert(now - 1000 <= cfg.stall_ms + 100);
  }
  {  // timeout: motion keeps happening but never converges (stall never trips)
    MoveConfig slow = cfg;
    slow.stall_ms = 10000000;  // disable stall for this case
    MoveController mc(slow);
    uint32_t now = 1000;
    float h = 75.0f;
    bool flip = false;
    mc.move_to(110.0f, h, now);
    while (mc.active() && now < 60000) {
      (void) mc.update(h, now);
      h += flip ? 0.1f : -0.1f;  // jitter in place forever
      flip = !flip;
      now += 10;
    }
    assert(mc.end_reason() == MoveEnd::TIMEOUT);
  }
  {  // tap limit: deadband unreachably tight -> gives up after max_taps
    MoveConfig tight = cfg;
    tight.deadband = 0.001f;  // display quantizes to 0.1, can't ever satisfy
    MoveController mc(tight);
    SimDesk sim{75.0f};
    uint32_t now = 1000;
    mc.move_to(90.05f, sim.display(), now);
    run_sim(mc, sim, now);
    assert(mc.end_reason() == MoveEnd::TAP_LIMIT);
  }
  {  // NaN current at start: waits, then proceeds once height appears
    MoveController mc(cfg);
    uint32_t now = 1000;
    mc.move_to(80.0f, NAN, now);
    assert(mc.update(NAN, now + 100) == 0);  // holds still while blind
    SimDesk sim{75.0f};
    now += 500;  // height arrives 500ms in (post-wake)
    run_sim(mc, sim, now);
    assert(mc.end_reason() == MoveEnd::DONE);
  }
}
```

- [ ] **Step 2: Run** — Expected: all pass immediately if Task 1's implementation is correct; any failure here is a real bug — fix `MoveController`, not the test.
- [ ] **Step 3: Commit** — `git add tests && git commit -m "test: MoveController abort/stall/timeout/tap-limit/blind-start paths"`

---

### Task 3: Glue integration (wire MoveController into DeskMitm)

**Files:**
- Modify: `components/desk_mitm/desk_mitm.h`
- Modify: `components/desk_mitm/desk_mitm.cpp`
- Modify: `components/desk_mitm/__init__.py`

- [ ] **Step 1: `desk_mitm.h` additions**

Add includes/members/methods (forward-declare the entity classes):

```cpp
// at top, after existing includes
namespace desk_mitm {
class DeskCover;
class DeskNumber;
```

Inside `class DeskMitm`, public section:

```cpp
  void set_move_config(float min_h, float max_h, float coast, float deadband,
                       uint32_t settle_ms, uint32_t timeout_ms, uint32_t stall_ms,
                       uint8_t max_taps) {
    move_cfg_.min_height = min_h;
    move_cfg_.max_height = max_h;
    move_cfg_.coast_margin = coast;
    move_cfg_.deadband = deadband;
    move_cfg_.settle_ms = settle_ms;
    move_cfg_.move_timeout_ms = timeout_ms;
    move_cfg_.stall_ms = stall_ms;
    move_cfg_.max_taps = max_taps;
    mover_.set_config(move_cfg_);
  }
  void set_cover(DeskCover *c) { cover_ = c; }
  void set_target_number(DeskNumber *n) { target_number_ = n; }

  void move_to_height(float cm);
  void move_to_position(float pos) {
    move_to_height(move_cfg_.min_height + pos * (move_cfg_.max_height - move_cfg_.min_height));
  }
  float position_from_height_(float h) const {
    float p = (h - move_cfg_.min_height) / (move_cfg_.max_height - move_cfg_.min_height);
    return p < 0 ? 0 : (p > 1 ? 1 : p);
  }
```

Protected members:

```cpp
  MoveConfig move_cfg_;
  MoveController mover_{move_cfg_};
  uint8_t mover_mask_{0};
  float pending_target_{NAN};  // move deferred until controller wakes
  DeskCover *cover_{nullptr};
  DeskNumber *target_number_{nullptr};
  void publish_cover_state_();
```

- [ ] **Step 2: `desk_mitm.cpp` changes**

Add include at top: `#include "desk_cover.h"` and `#include "desk_number.h"` (created in Task 4; to keep this task compiling standalone, guard the two publish sites with `if (cover_ != nullptr)` — the pointers stay null until Task 4 wires them).

In `loop()`, after the UART drains and before the watchdog block:

```cpp
  // Tick the move engine once per loop; poll replies read mover_mask_.
  {
    const uint32_t t = millis();
    bool was_active = mover_.active();
    mover_mask_ = mover_.update(height_, t);
    if (was_active && !mover_.active()) {
      ESP_LOGI(TAG, "move ended: %d (height %.1f)", (int) mover_.end_reason(), height_);
      publish_cover_state_();
    }
  }
```

In `handle_desk_frame_` case `0x11`, next to the pending-injection start:

```cpp
      if (!std::isnan(pending_target_)) {  // wake-deferred move starts now
        mover_.move_to(pending_target_, height_, now);
        pending_target_ = NAN;
      }
```

In `handle_desk_frame_` case `0x12`, after `last_height_change_ms_ = now;` add `publish_cover_state_();`

In `handle_keypad_frame_`, type `0x02` branch — physical override:

```cpp
    if (f.payload[0] != 0 && mover_.active()) {
      ESP_LOGI(TAG, "physical key %02X overrides move-to-height; aborting", f.payload[0]);
      mover_.abort();
    }
```

In `reply_to_poll_`, emulation branch becomes:

```cpp
  uint8_t mask = mover_.active() ? mover_mask_ : keys_.current(now);
  auto reply = build_key_reply(mask);
  desk_->write_array(reply.data(), reply.size());
```

In `failsafe_clear_`: add `mover_.abort(); pending_target_ = NAN;`
In `stop()`: add `mover_.abort();` as the first line.
In `update_pin20_`: extend the hold condition — wake also held while `mover_.active() || !std::isnan(pending_target_)`.

New methods:

```cpp
void DeskMitm::move_to_height(float cm) {
  const uint32_t now = millis();
  if (!emulation_) {
    ESP_LOGW(TAG, "move_to_height ignored: emulation mode is off");
    return;
  }
  if (polling_) {
    if (mover_.move_to(cm, height_, now)) ESP_LOGI(TAG, "move_to %.1f cm", cm);
    return;
  }
  ESP_LOGI(TAG, "controller asleep; waking for move_to %.1f cm", cm);
  pending_target_ = cm;
  wake_request_ = true;
  wake_started_ms_ = now;
}

void DeskMitm::publish_cover_state_() { /* filled in Task 4; no-op until entities exist */
}
```

- [ ] **Step 3: `__init__.py` config options** — extend `CONFIG_SCHEMA` dict:

```python
        cv.Optional("min_height", default=60.0): cv.float_,
        cv.Optional("max_height", default=121.0): cv.float_,
        cv.Optional("coast_margin", default=0.7): cv.float_,
        cv.Optional("deadband", default=0.3): cv.float_,
        cv.Optional("settle_ms", default=1200): cv.positive_int,
        cv.Optional("move_timeout_ms", default=30000): cv.positive_int,
        cv.Optional("stall_ms", default=2000): cv.positive_int,
        cv.Optional("max_taps", default=5): cv.positive_int,
```

and in `to_code`:

```python
    cg.add(
        var.set_move_config(
            config["min_height"], config["max_height"], config["coast_margin"],
            config["deadband"], config["settle_ms"], config["move_timeout_ms"],
            config["stall_ms"], config["max_taps"],
        )
    )
```

- [ ] **Step 4: Gates** — host tests still pass; `esphome compile desk-mitm.yaml` succeeds (entities not in YAML yet).
- [ ] **Step 5: Commit** — `git add components && git commit -m "feat: wire MoveController into desk_mitm glue with wake, override and fail-safe aborts"`

---

### Task 4: Cover + number platforms, YAML, compile

**Files:**
- Create: `components/desk_mitm/desk_cover.h`
- Create: `components/desk_mitm/desk_number.h`
- Create: `components/desk_mitm/cover.py`
- Create: `components/desk_mitm/number.py`
- Modify: `components/desk_mitm/desk_mitm.cpp` (fill `publish_cover_state_`)
- Modify: `desk-mitm.yaml`

- [ ] **Step 1: `desk_cover.h`**

```cpp
#pragma once
#include "esphome/core/component.h"
#include "esphome/components/cover/cover.h"
#include "desk_mitm.h"

namespace desk_mitm {

class DeskCover : public esphome::cover::Cover, public esphome::Component {
 public:
  void set_parent(DeskMitm *p) { parent_ = p; }
  esphome::cover::CoverTraits get_traits() override {
    auto t = esphome::cover::CoverTraits();
    t.set_supports_position(true);
    t.set_supports_stop(true);
    return t;
  }

 protected:
  void control(const esphome::cover::CoverCall &call) override {
    if (call.get_stop()) parent_->stop();
    if (call.get_position().has_value()) parent_->move_to_position(*call.get_position());
  }
  DeskMitm *parent_{nullptr};
};

}  // namespace desk_mitm
```

- [ ] **Step 2: `desk_number.h`**

```cpp
#pragma once
#include "esphome/core/component.h"
#include "esphome/components/number/number.h"
#include "desk_mitm.h"

namespace desk_mitm {

class DeskNumber : public esphome::number::Number, public esphome::Component {
 public:
  void set_parent(DeskMitm *p) { parent_ = p; }

 protected:
  void control(float value) override {
    parent_->move_to_height(value);
    this->publish_state(value);
  }
  DeskMitm *parent_{nullptr};
};

}  // namespace desk_mitm
```

- [ ] **Step 3: fill `publish_cover_state_` in `desk_mitm.cpp`**

```cpp
void DeskMitm::publish_cover_state_() {
  if (cover_ == nullptr || std::isnan(height_)) return;
  float pos = position_from_height_(height_);
  int dir = mover_.active() ? mover_.direction(height_) : 0;
  auto op = dir > 0   ? esphome::cover::COVER_OPERATION_OPENING
            : dir < 0 ? esphome::cover::COVER_OPERATION_CLOSING
                      : esphome::cover::COVER_OPERATION_IDLE;
  if (pos != cover_->position || op != cover_->current_operation) {
    cover_->position = pos;
    cover_->current_operation = op;
    cover_->publish_state();
  }
}
```

- [ ] **Step 4: `cover.py`**

```python
import esphome.codegen as cg
import esphome.config_validation as cv
from esphome.components import cover
from . import DeskMitm, desk_mitm_ns

DEPENDENCIES = ["desk_mitm"]
CONF_DESK_MITM_ID = "desk_mitm_id"

DeskCover = desk_mitm_ns.class_("DeskCover", cover.Cover, cg.Component)

CONFIG_SCHEMA = cover.cover_schema(DeskCover).extend(
    {cv.GenerateID(CONF_DESK_MITM_ID): cv.use_id(DeskMitm)}
).extend(cv.COMPONENT_SCHEMA)

async def to_code(config):
    var = await cover.new_cover(config)
    await cg.register_component(var, config)
    parent = await cg.get_variable(config[CONF_DESK_MITM_ID])
    cg.add(var.set_parent(parent))
    cg.add(parent.set_cover(var))
```

- [ ] **Step 5: `number.py`**

```python
import esphome.codegen as cg
import esphome.config_validation as cv
from esphome.components import number
from esphome.const import CONF_MAX_VALUE, CONF_MIN_VALUE, CONF_STEP
from . import DeskMitm, desk_mitm_ns

DEPENDENCIES = ["desk_mitm"]
CONF_DESK_MITM_ID = "desk_mitm_id"

DeskNumber = desk_mitm_ns.class_("DeskNumber", number.Number, cg.Component)

CONFIG_SCHEMA = number.number_schema(DeskNumber).extend(
    {
        cv.GenerateID(CONF_DESK_MITM_ID): cv.use_id(DeskMitm),
        cv.Optional(CONF_MIN_VALUE, default=60.0): cv.float_,
        cv.Optional(CONF_MAX_VALUE, default=121.0): cv.float_,
        cv.Optional(CONF_STEP, default=0.1): cv.positive_float,
    }
).extend(cv.COMPONENT_SCHEMA)

async def to_code(config):
    var = await number.new_number(
        config,
        min_value=config[CONF_MIN_VALUE],
        max_value=config[CONF_MAX_VALUE],
        step=config[CONF_STEP],
    )
    await cg.register_component(var, config)
    parent = await cg.get_variable(config[CONF_DESK_MITM_ID])
    cg.add(var.set_parent(parent))
    cg.add(parent.set_target_number(var))
```

Note: `desk_mitm.cpp` includes `desk_cover.h`/`desk_number.h`; ESPHome compiles all files in the component dir, and the platform classes are header-only, so no extra build config is needed. If `cover.cover_schema(...)`/`number.number_schema(...)` don't exist in the installed ESPHome (API drift), check `.esphome` build cache of another project or the installed package source for the current names (`COVER_SCHEMA` etc.) and adapt — the C++ side is version-stable.

- [ ] **Step 6: `desk-mitm.yaml`** — add substitutions at the top and entities:

```yaml
substitutions:
  # UNCALIBRATED placeholders — set from the calibration step (Task 5)
  min_height: "60.0"
  max_height: "121.0"
```

Extend the `desk_mitm:` block:

```yaml
  min_height: ${min_height}
  max_height: ${max_height}
```

New top-level blocks:

```yaml
cover:
  - platform: desk_mitm
    name: "Desk"
    device_class: none
    icon: mdi:desk

number:
  - platform: desk_mitm
    name: "Target Height"
    unit_of_measurement: "cm"
    icon: mdi:human-male-height
    mode: box
    min_value: ${min_height}
    max_value: ${max_height}
    step: 0.1
```

- [ ] **Step 7: Gates** — host tests pass; `esphome config desk-mitm.yaml` valid; `esphome compile desk-mitm.yaml` succeeds.
- [ ] **Step 8: Commit** — `git add components desk-mitm.yaml && git commit -m "feat: desk cover and target-height number platforms"`

---

### Task 5: Calibration + live verification

**Files:**
- Modify: `desk-mitm.yaml` (real min/max)

- [ ] **Step 1: Flash** — `esphome run desk-mitm.yaml --device 192.168.40.65 --no-logs` → `OTA successful`.
- [ ] **Step 2: Calibrate** — user jogs (physical keypad) to the very bottom, notes height; then to the very top, notes height. Update the two substitutions, reflash. (Until then the entities work with placeholder rails — just don't trust position 0/1 extremes.)
- [ ] **Step 3: Live checks** (mix of REST/HA driving and user observation):
  - Number: set Target Height to a value ~10 cm away → desk lands within ±0.3 cm (read the sensor).
  - Cover: slider to 50% → desk goes to mid-range; open → top; close → bottom; stop mid-travel → halts.
  - Physical override: start a cover move, press a keypad key → move aborts instantly, keypad command wins.
  - Cold start: with desk asleep, set a target → wakes, moves, sleeps.
- [ ] **Step 4: Commit** — `git add desk-mitm.yaml && git commit -m "feat: calibrated desk travel range"`

---

### Task 6: Docs + close out

**Files:**
- Modify: `README.md`
- Create: `docs/superpowers/specs/2026-08-08-phase3-findings.md`

- [ ] **Step 1: README** — entity list gains the cover + number; add a short "ESP8266 compatibility" note (1 hardware RX → keypad side on software serial, `logger: baud_rate: 0`, drop `web_server`; ESP32 remains the recommendation); mention the closed-loop tunables (substitutions) in one sentence.
- [ ] **Step 2: Findings doc** — measured accuracy over several moves (target vs landed), any tuning changes to coast/deadband defaults, override/cold-start behavior, tap effectiveness.
- [ ] **Step 3: Commit + push** — `git add README.md docs && git commit -m "docs: phase 3 findings and README updates" && git push`

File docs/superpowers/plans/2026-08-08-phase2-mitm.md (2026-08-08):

# Phase 2 Active MITM Implementation Plan

> **For agentic workers:** REQUIRED SUB-SKILL: Use superpowers:subagent-driven-development (recommended) or superpowers:executing-plans to implement this plan task-by-task. Steps use checkbox (`- [ ]`) syntax for tracking.

**Goal:** ESP32 keypad-emulation MITM: keypad stays fully functional, HA gets height sensor + up/down/stop/preset buttons + deterministic wake.

**Architecture:** Per `docs/superpowers/specs/2026-08-08-phase2-mitm-design.md` (rev 2). Only RJ45 lines 6 (keypad→controller UART) and 4 (PIN 20) are cut; controller→keypad line 5 stays intact and tapped. Pure protocol logic lives in `components/desk_mitm/protocol.h`, unit-tested on the host against frames from `captures/2026-08-08-session1.log`; a thin ESPHome component wires it to UARTs/GPIOs.

**Tech Stack:** ESPHome external component (C++/esp-idf), host-side tests with plain `assert` via `c++ -std=c++17`, existing BSS138 shifter (4 ch) + 4.7k/10k divider.

**Protocol facts used throughout** (ground truth: `docs/superpowers/specs/2026-08-08-phase1-findings.md`):
- Frame: `9B <len> <type> <payload…> <crc_hi> <crc_lo> 9D`; `len` counts everything after itself including the trailing `9D`; CRC-16/MODBUS over `[len, type, payload…]`, transmitted **high byte first** (verified: `crc16([04,11]) = 0x7CC3` → wire bytes `7C C3`).
- Poll `9B:04:11:7C:C3:9D` (controller, ~31 Hz) → reply `9B:06:02:<keys>:00:<crc>:9D` (keypad). Keys: up=01 down=02 p1=04 p2=08 p3=10 M=20.
- Display `9B:07:12:<d0>:<d1>:<d2>:<crc>:9D`, 7-segment, bit7=decimal point.
- Keepalive `9B:04:15:BF:C2:9D`; shutdown burst `9B:04:13:BD:42:9D` then PIN 20 falls.

---

### Task 1: Scaffolding + CRC16 (TDD)

**Files:**
- Create: `components/desk_mitm/protocol.h`
- Create: `tests/test_protocol.cpp`
- Modify: `.gitignore` (add `build/`)

- [ ] **Step 1: Write the failing CRC test**

`tests/test_protocol.cpp`:
```cpp
#include "../components/desk_mitm/protocol.h"
#include <cassert>
#include <cstdio>
#include <cmath>

using namespace desk_mitm;

static void test_crc16() {
  // Vectors straight from captures/2026-08-08-session1.log
  const uint8_t poll[] = {0x04, 0x11};
  assert(crc16(poll, 2) == 0x7CC3);
  const uint8_t idle[] = {0x06, 0x02, 0x00, 0x00};
  assert(crc16(idle, 4) == 0x6CA1);
  const uint8_t disp[] = {0x07, 0x12, 0x07, 0xEF, 0x6D};
  assert(crc16(disp, 5) == 0xA4A8);
}

int main() {
  test_crc16();
  printf("all tests passed\n");
  return 0;
}
```

- [ ] **Step 2: Run to verify it fails**

Run: `mkdir -p build && c++ -std=c++17 -o build/test_protocol tests/test_protocol.cpp && ./build/test_protocol`
Expected: FAIL to compile — `protocol.h` does not exist.

- [ ] **Step 3: Implement CRC in `components/desk_mitm/protocol.h`**

```cpp
#pragma once
#include <cstdint>
#include <cstddef>
#include <vector>

namespace desk_mitm {

// CRC-16/MODBUS (init 0xFFFF, poly 0xA001 reflected).
inline uint16_t crc16(const uint8_t *data, size_t len) {
  uint16_t crc = 0xFFFF;
  for (size_t i = 0; i < len; i++) {
    crc ^= data[i];
    for (int b = 0; b < 8; b++)
      crc = (crc & 1) ? (crc >> 1) ^ 0xA001 : (crc >> 1);
  }
  return crc;
}

}  // namespace desk_mitm
```

- [ ] **Step 4: Run test to verify it passes**

Run: `c++ -std=c++17 -o build/test_protocol tests/test_protocol.cpp && ./build/test_protocol`
Expected: `all tests passed`. If the three asserts disagree on CRC span/byte-order, the captured frames win — adjust span, never the vectors.

- [ ] **Step 5: Commit**

```bash
echo "build/" >> .gitignore
git add components tests .gitignore && git commit -m "feat: desk_mitm protocol CRC16 with captured test vectors"
```

---

### Task 2: Frame parser (TDD)

**Files:**
- Modify: `components/desk_mitm/protocol.h`
- Modify: `tests/test_protocol.cpp`

- [ ] **Step 1: Add failing parser tests to `tests/test_protocol.cpp`** (call from `main`)

```cpp
static void test_parser() {
  Parser p;
  Frame f;
  // Clean poll frame parses.
  const uint8_t poll[] = {0x9B, 0x04, 0x11, 0x7C, 0xC3, 0x9D};
  int emitted = 0;
  for (uint8_t b : poll)
    if (p.feed(b, f)) emitted++;
  assert(emitted == 1 && f.type == 0x11 && f.payload.empty());

  // Garbage prefix (wake transients) is skipped; frame still parses.
  const uint8_t noisy[] = {0x00, 0xFE, 0x9B, 0x06, 0x02, 0x01, 0x00, 0xFC, 0xA0, 0x9D};
  emitted = 0;
  for (uint8_t b : noisy)
    if (p.feed(b, f)) emitted++;
  assert(emitted == 1 && f.type == 0x02);
  assert(f.payload.size() == 2 && f.payload[0] == 0x01 && f.payload[1] == 0x00);

  // Corrupted CRC (captured power-down tail had 42:FD instead of 42:9D) is dropped.
  const uint8_t bad[] = {0x9B, 0x04, 0x13, 0xBD, 0x42, 0xFD};
  emitted = 0;
  for (uint8_t b : bad)
    if (p.feed(b, f)) emitted++;
  assert(emitted == 0);

  // Parser recovers after garbage: next clean frame parses.
  const uint8_t disp[] = {0x9B, 0x07, 0x12, 0x07, 0xEF, 0x6D, 0xA4, 0xA8, 0x9D};
  emitted = 0;
  for (uint8_t b : disp)
    if (p.feed(b, f)) emitted++;
  assert(emitted == 1 && f.type == 0x12 && f.payload.size() == 3);

  // raw() returns the full frame bytes for verbatim forwarding.
  assert(f.raw.size() == 9 && f.raw[0] == 0x9B && f.raw[8] == 0x9D);
}
```

- [ ] **Step 2: Run to verify it fails**

Run: `c++ -std=c++17 -o build/test_protocol tests/test_protocol.cpp && ./build/test_protocol`
Expected: compile error — `Parser` not defined.

- [ ] **Step 3: Implement `Frame` and `Parser` in `protocol.h`**

```cpp
struct Frame {
  uint8_t type{0};
  std::vector<uint8_t> payload;  // bytes between type and CRC
  std::vector<uint8_t> raw;      // full frame incl. 9B..9D, for verbatim forwarding
};

// Byte-driven parser. len counts type+payload+crc+terminator (everything after len).
// Emits only CRC-valid, 9D-terminated frames; anything else resyncs on next 9B.
class Parser {
 public:
  // Returns true when `out` holds a complete valid frame.
  bool feed(uint8_t b, Frame &out) {
    switch (state_) {
      case State::SYNC:
        if (b == 0x9B) { buf_.assign(1, 0x9B); state_ = State::LEN; }
        return false;
      case State::LEN:
        // Sane length: type+crc2+9D = 4 minimum, cap payload at 8 bytes.
        if (b < 4 || b > 12) { state_ = State::SYNC; return false; }
        len_ = b;
        buf_.push_back(b);
        state_ = State::BODY;
        return false;
      case State::BODY:
        buf_.push_back(b);
        if (buf_.size() < static_cast<size_t>(len_) + 2) return false;
        state_ = State::SYNC;
        return finish_(out);
    }
    return false;
  }

 private:
  bool finish_(Frame &out) {
    // buf_ = 9B len type payload... crc_hi crc_lo 9D
    if (buf_.back() != 0x9D) return false;
    size_t n = buf_.size();
    uint16_t crc = crc16(buf_.data() + 1, n - 4);  // over [len, type, payload]
    if (buf_[n - 3] != (crc >> 8) || buf_[n - 2] != (crc & 0xFF)) return false;
    out.type = buf_[2];
    out.payload.assign(buf_.begin() + 3, buf_.end() - 3);
    out.raw = buf_;
    return true;
  }

  enum class State { SYNC, LEN, BODY } state_{State::SYNC};
  uint8_t len_{0};
  std::vector<uint8_t> buf_;
};
```

- [ ] **Step 4: Run tests**

Run: `c++ -std=c++17 -o build/test_protocol tests/test_protocol.cpp && ./build/test_protocol`
Expected: `all tests passed`

- [ ] **Step 5: Commit**

```bash
git add components tests && git commit -m "feat: desk_mitm frame parser with capture-derived tests"
```

---

### Task 3: Height decoder + reply builder (TDD)

**Files:**
- Modify: `components/desk_mitm/protocol.h`
- Modify: `tests/test_protocol.cpp`

- [ ] **Step 1: Add failing tests** (call from `main`)

```cpp
static void test_height() {
  // Captured vectors: 07:EF:6D = "79.5", 07:ED:3F = "75.0"
  const uint8_t h795[] = {0x07, 0xEF, 0x6D};
  assert(std::fabs(decode_height(h795) - 79.5f) < 0.01f);
  const uint8_t h750[] = {0x07, 0xED, 0x3F};
  assert(std::fabs(decode_height(h750) - 75.0f) < 0.01f);
  // 3-digit, no decimal point: 06:5B:06 = "121"
  const uint8_t h121[] = {0x06, 0x5B, 0x06};
  assert(std::fabs(decode_height(h121) - 121.0f) < 0.01f);
  // M-mode prompt "S- " is not a height.
  const uint8_t prompt[] = {0x6D, 0x40, 0x00};
  assert(std::isnan(decode_height(prompt)));
}

static void test_build_reply() {
  // Idle reply must byte-match the captured keypad frame.
  auto idle = build_key_reply(0x00);
  const uint8_t expect[] = {0x9B, 0x06, 0x02, 0x00, 0x00, 0x6C, 0xA1, 0x9D};
  assert(idle.size() == 8);
  for (int i = 0; i < 8; i++) assert(idle[i] == expect[i]);
  // Up reply matches captured 9B:06:02:01:00:FC:A0:9D.
  auto up = build_key_reply(0x01);
  assert(up[3] == 0x01 && up[5] == 0xFC && up[6] == 0xA0);
}
```

- [ ] **Step 2: Run to verify failure**

Run: `c++ -std=c++17 -o build/test_protocol tests/test_protocol.cpp && ./build/test_protocol`
Expected: compile error — `decode_height` / `build_key_reply` not defined.

- [ ] **Step 3: Implement in `protocol.h`**

```cpp
#include <cmath>

// 7-segment glyph -> digit value, ignoring the decimal-point bit (bit 7). -1 = not a digit.
inline int seg_digit(uint8_t b) {
  switch (b & 0x7F) {
    case 0x3F: return 0; case 0x06: return 1; case 0x5B: return 2;
    case 0x4F: return 3; case 0x66: return 4; case 0x6D: return 5;
    case 0x7D: return 6; case 0x07: return 7; case 0x7F: return 8;
    case 0x6F: return 9; default: return -1;
  }
}

// Decode a type-12 payload (3 display bytes) to height. NAN when not numeric
// (M-mode "S-" prompt, blanks). Middle-digit decimal point => XX.X, else XXX.
inline float decode_height(const uint8_t *p) {
  int d0 = seg_digit(p[0]), d1 = seg_digit(p[1]), d2 = seg_digit(p[2]);
  if (d0 < 0 || d1 < 0 || d2 < 0) return NAN;
  if (p[1] & 0x80) return d0 * 10.0f + d1 + d2 * 0.1f;
  return d0 * 100.0f + d1 * 10.0f + d2 * 1.0f;
}

// Build a keypad type-02 reply frame for a key bitmask.
inline std::vector<uint8_t> build_key_reply(uint8_t keys) {
  std::vector<uint8_t> f = {0x9B, 0x06, 0x02, keys, 0x00};
  uint16_t crc = crc16(f.data() + 1, 4);
  f.push_back(crc >> 8);
  f.push_back(crc & 0xFF);
  f.push_back(0x9D);
  return f;
}
```

Note: the `0x6D` glyph is both '5' and 'S' — `decode_height` returns NAN for the prompt because its *other* bytes (`0x40` '-', `0x00` blank) are non-digits. The captured "121" vector pins the no-decimal-point path.

- [ ] **Step 4: Run tests**

Run: `c++ -std=c++17 -o build/test_protocol tests/test_protocol.cpp && ./build/test_protocol`
Expected: `all tests passed`

- [ ] **Step 5: Commit**

```bash
git add components tests && git commit -m "feat: desk_mitm height decoder and reply builder"
```

---

### Task 4: Key-state model with fail-safes (TDD)

**Files:**
- Modify: `components/desk_mitm/protocol.h`
- Modify: `tests/test_protocol.cpp`

- [ ] **Step 1: Add failing tests** (call from `main`)

```cpp
static void test_key_state() {
  KeyState k;
  // Default idle.
  assert(k.current(1000) == 0x00);
  // Real keys pass through.
  k.set_real(0x01);
  assert(k.current(1000) == 0x01);
  // Injection REPLACES real keys (never ORs).
  k.inject(0x04, 150, 1000);
  assert(k.current(1010) == 0x04);
  // Injection expires by deadline even with no further events.
  assert(k.current(1200) == 0x01);
  // stop() clears injection immediately.
  k.inject(0x04, 150, 2000);
  k.stop();
  assert(k.current(2010) == 0x01);
  // clear_all releases everything (fail-safe path).
  k.clear_all();
  assert(k.current(2020) == 0x00);
  // Invalid masks are rejected: multi-bit and opposing directions never emitted.
  assert(!k.inject(0x03, 150, 3000));
  assert(!k.inject(0xC0, 150, 3000));
  assert(k.current(3010) == 0x00);
  // Valid single-key masks accepted.
  assert(k.inject(0x10, 150, 4000));
  assert(k.current(4010) == 0x10);
}
```

- [ ] **Step 2: Run to verify failure**

Run: `c++ -std=c++17 -o build/test_protocol tests/test_protocol.cpp && ./build/test_protocol`
Expected: compile error — `KeyState` not defined.

- [ ] **Step 3: Implement `KeyState` in `protocol.h`**

```cpp
// Local key-state model. Injection replaces physical keys for its bounded
// window; fail-safe callers use clear_all() (poll timeout, CRC storm, type-13,
// PIN20 fall, reboot paths are the ESPHome layer's responsibility).
class KeyState {
 public:
  void set_real(uint8_t mask) { real_ = mask; }

  // Only idle or a single documented key may be injected.
  bool inject(uint8_t mask, uint32_t duration_ms, uint32_t now_ms) {
    static constexpr uint8_t VALID[] = {0x01, 0x02, 0x04, 0x08, 0x10, 0x20};
    bool ok = false;
    for (uint8_t v : VALID) ok |= (mask == v);
    if (!ok) return false;
    inj_ = mask;
    inj_deadline_ = now_ms + duration_ms;
    inj_active_ = true;
    return true;
  }

  void stop() { inj_active_ = false; }
  void clear_all() { inj_active_ = false; real_ = 0; }

  uint8_t current(uint32_t now_ms) {
    if (inj_active_ && now_ms >= inj_deadline_) inj_active_ = false;
    return inj_active_ ? inj_ : real_;
  }

  bool injection_active(uint32_t now_ms) {
    if (inj_active_ && now_ms >= inj_deadline_) inj_active_ = false;
    return inj_active_;
  }

 private:
  uint8_t real_{0}, inj_{0};
  uint32_t inj_deadline_{0};
  bool inj_active_{false};
};
```

- [ ] **Step 4: Run tests**

Run: `c++ -std=c++17 -o build/test_protocol tests/test_protocol.cpp && ./build/test_protocol`
Expected: `all tests passed`

- [ ] **Step 5: Commit**

```bash
git add components tests && git commit -m "feat: desk_mitm key-state model with injection bounds and fail-safe clear"
```

---

### Task 5: ESPHome component glue + node config

**Files:**
- Create: `components/desk_mitm/__init__.py`
- Create: `components/desk_mitm/desk_mitm.h`
- Create: `components/desk_mitm/desk_mitm.cpp`
- Create: `desk-mitm.yaml`

- [ ] **Step 1: Write `components/desk_mitm/__init__.py`**

```python
import esphome.codegen as cg
import esphome.config_validation as cv
from esphome import pins
from esphome.components import uart
from esphome.const import CONF_ID

DEPENDENCIES = ["uart"]

desk_mitm_ns = cg.esphome_ns.namespace("desk_mitm")
DeskMitm = desk_mitm_ns.class_("DeskMitm", cg.Component)

CONF_DESK_UART = "desk_uart"
CONF_KEYPAD_UART = "keypad_uart"
CONF_PIN20_SENSE = "pin20_sense_pin"
CONF_PIN20_DRIVE = "pin20_drive_pin"

CONFIG_SCHEMA = cv.Schema(
    {
        cv.GenerateID(): cv.declare_id(DeskMitm),
        cv.Required(CONF_DESK_UART): cv.use_id(uart.UARTComponent),
        cv.Required(CONF_KEYPAD_UART): cv.use_id(uart.UARTComponent),
        cv.Required(CONF_PIN20_SENSE): pins.gpio_input_pin_schema,
        cv.Required(CONF_PIN20_DRIVE): pins.gpio_output_pin_schema,
    }
).extend(cv.COMPONENT_SCHEMA)

async def to_code(config):
    var = cg.new_Pvariable(config[CONF_ID])
    await cg.register_component(var, config)
    desk = await cg.get_variable(config[CONF_DESK_UART])
    keypad = await cg.get_variable(config[CONF_KEYPAD_UART])
    cg.add(var.set_uarts(desk, keypad))
    sense = await cg.gpio_pin_expression(config[CONF_PIN20_SENSE])
    drive = await cg.gpio_pin_expression(config[CONF_PIN20_DRIVE])
    cg.add(var.set_pin20(sense, drive))
```

- [ ] **Step 2: Write `components/desk_mitm/desk_mitm.h`**

```cpp
#pragma once
#include "esphome/core/component.h"
#include "esphome/core/hal.h"
#include "esphome/components/uart/uart.h"
#include "protocol.h"

namespace desk_mitm {

class DeskMitm : public esphome::Component {
 public:
  void set_uarts(esphome::uart::UARTComponent *desk, esphome::uart::UARTComponent *keypad) {
    desk_ = desk;
    keypad_ = keypad;
  }
  void set_pin20(esphome::GPIOPin *sense, esphome::GPIOPin *drive) {
    pin20_sense_ = sense;
    pin20_drive_ = drive;
  }

  void setup() override;
  void loop() override;
  float get_setup_priority() const override { return esphome::setup_priority::DATA; }

  // Called from YAML template buttons / switch.
  void inject(uint8_t mask, uint32_t duration_ms);
  void stop();
  void set_emulation(bool on) { emulation_ = on; }

  float get_height() const { return height_; }
  bool get_controller_polling() const { return polling_; }

 protected:
  void handle_desk_frame_(const Frame &f);
  void handle_keypad_frame_(const Frame &f);
  void reply_to_poll_();
  void update_pin20_();
  void failsafe_clear_(const char *reason);

  esphome::uart::UARTComponent *desk_{nullptr};
  esphome::uart::UARTComponent *keypad_{nullptr};
  esphome::GPIOPin *pin20_sense_{nullptr};
  esphome::GPIOPin *pin20_drive_{nullptr};

  Parser desk_parser_, keypad_parser_;
  KeyState keys_;

  bool emulation_{false};  // false = echo mode
  std::vector<uint8_t> last_real_reply_;
  uint32_t last_real_reply_ms_{0};

  float height_{NAN};
  uint32_t last_height_change_ms_{0};
  uint32_t last_poll_ms_{0};
  bool polling_{false};

  bool sense_state_{false};
  uint32_t sense_rise_ms_{0};

  bool wake_request_{false};
  uint8_t pending_mask_{0};
  uint32_t pending_duration_{0};
  uint32_t wake_started_ms_{0};
};

}  // namespace desk_mitm
```

- [ ] **Step 3: Write `components/desk_mitm/desk_mitm.cpp`**

```cpp
#include "desk_mitm.h"
#include "esphome/core/log.h"

namespace desk_mitm {

static const char *const TAG = "desk_mitm";
using esphome::millis;

void DeskMitm::setup() {
  pin20_sense_->setup();
  pin20_drive_->setup();
  pin20_drive_->digital_write(false);
}

void DeskMitm::loop() {
  const uint32_t now = millis();

  // PIN 20 sense edges.
  bool s = pin20_sense_->digital_read();
  if (s && !sense_state_) sense_rise_ms_ = now;
  if (!s && sense_state_) failsafe_clear_("pin20 fell");
  sense_state_ = s;

  // Drain desk-side UART (controller talking on the pin-5 tap).
  uint8_t b;
  Frame f;
  while (desk_->available()) {
    desk_->read_byte(&b);
    if (desk_parser_.feed(b, f)) handle_desk_frame_(f);
  }
  // Drain keypad-side UART.
  while (keypad_->available()) {
    keypad_->read_byte(&b);
    if (keypad_parser_.feed(b, f)) handle_keypad_frame_(f);
  }

  // Poll watchdog: 500 ms of silence clears everything.
  if (polling_ && now - last_poll_ms_ > 500) {
    polling_ = false;
    failsafe_clear_("poll timeout");
  }
  // Wake timeout: controller never started polling.
  if (wake_request_ && pending_mask_ != 0 && now - wake_started_ms_ > 2000 && !polling_) {
    ESP_LOGW(TAG, "wake timeout: controller did not start polling; dropping injection");
    pending_mask_ = 0;
    wake_request_ = false;
  }
  update_pin20_();
}

void DeskMitm::handle_desk_frame_(const Frame &f) {
  const uint32_t now = millis();
  switch (f.type) {
    case 0x11:  // poll
      if (!polling_) ESP_LOGI(TAG, "controller polling started");
      polling_ = true;
      last_poll_ms_ = now;
      if (pending_mask_ != 0) {  // wake-deferred injection starts now
        keys_.inject(pending_mask_, pending_duration_, now);
        pending_mask_ = 0;
      }
      reply_to_poll_();
      break;
    case 0x12: {  // display
      if (f.payload.size() == 3) {
        float h = decode_height(f.payload.data());
        if (!std::isnan(h) && h != height_) {
          height_ = h;
          last_height_change_ms_ = now;
        }
      }
      break;
    }
    case 0x13:  // shutdown announcement
      failsafe_clear_("controller shutdown");
      polling_ = false;
      break;
    default:
      break;  // keepalive 0x15 etc: keypad hears these directly on intact pin 5
  }
}

void DeskMitm::handle_keypad_frame_(const Frame &f) {
  const uint32_t now = millis();
  // Squelch wake transients for 300 ms after PIN 20 rise.
  if (sense_state_ && now - sense_rise_ms_ < 300) return;
  if (f.type == 0x02 && f.payload.size() == 2) {
    keys_.set_real(f.payload[0]);
    last_real_reply_ = f.raw;
    last_real_reply_ms_ = now;
  } else {
    // Unknown keypad frame (programming etc.): forward verbatim.
    desk_->write_array(f.raw.data(), f.raw.size());
    ESP_LOGI(TAG, "forwarded keypad frame type=%02X len=%u", f.type, (unsigned) f.raw.size());
  }
}

void DeskMitm::reply_to_poll_() {
  const uint32_t now = millis();
  if (!emulation_) {
    // Echo mode: replay the keypad's latest reply if fresh, else synthesize idle.
    if (!last_real_reply_.empty() && now - last_real_reply_ms_ < 500) {
      desk_->write_array(last_real_reply_.data(), last_real_reply_.size());
      return;
    }
    auto idle = build_key_reply(0x00);
    desk_->write_array(idle.data(), idle.size());
    return;
  }
  auto reply = build_key_reply(keys_.current(now));
  desk_->write_array(reply.data(), reply.size());
}

void DeskMitm::inject(uint8_t mask, uint32_t duration_ms) {
  const uint32_t now = millis();
  if (!emulation_) {
    ESP_LOGW(TAG, "injection ignored: emulation mode is off");
    return;
  }
  if (polling_) {
    if (!keys_.inject(mask, duration_ms, now)) ESP_LOGW(TAG, "invalid mask %02X", mask);
    return;
  }
  ESP_LOGI(TAG, "controller asleep; raising PIN20 and deferring injection %02X", mask);
  pending_mask_ = mask;
  pending_duration_ = duration_ms;
  wake_request_ = true;
  wake_started_ms_ = now;
}

void DeskMitm::stop() { keys_.stop(); }

void DeskMitm::update_pin20_() {
  const uint32_t now = millis();
  // Hold our wake while: injection pending/active, or height still settling.
  bool moving_recently = now - last_height_change_ms_ < 1000;
  if (wake_request_ && pending_mask_ == 0 && !keys_.injection_active(now) && !moving_recently)
    wake_request_ = false;
  // Mirror keypad wake; OR in our own.
  pin20_drive_->digital_write(sense_state_ || wake_request_);
}

void DeskMitm::failsafe_clear_(const char *reason) {
  keys_.clear_all();
  pending_mask_ = 0;
  ESP_LOGD(TAG, "key state cleared (%s)", reason);
}

}  // namespace desk_mitm
```

- [ ] **Step 4: Write `desk-mitm.yaml`**

```yaml
esphome:
  name: desk-sniffer
  friendly_name: Flexispot Desk

esp32:
  board: esp32dev
  framework:
    type: esp-idf

external_components:
  - source:
      type: local
      path: components

logger:
  level: DEBUG

api:

ota:
  - platform: esphome

wifi:
  ssid: !secret wifi_ssid
  password: !secret wifi_password
  use_address: 192.168.40.65
  ap:
    ssid: "Desk-Sniffer Fallback"

captive_portal:

uart:
  - id: uart_desk    # RX: controller TX tap (RJ45 pin 5, desk side); TX: controller RX (pin 6, desk side)
    rx_pin: GPIO17
    tx_pin: GPIO26
    baud_rate: 9600
  - id: uart_keypad  # RX only: keypad TX (RJ45 pin 6, keypad side)
    rx_pin: GPIO16
    baud_rate: 9600

desk_mitm:
  id: mitm
  desk_uart: uart_desk
  keypad_uart: uart_keypad
  pin20_sense_pin:
    number: GPIO34
    allow_other_uses: true
    mode:
      input: true
  pin20_drive_pin:
    number: GPIO27
    mode:
      output: true

binary_sensor:
  - platform: gpio
    pin:
      number: GPIO34
      allow_other_uses: true
      mode:
        input: true
    name: "PIN 20"
    id: pin20
  - platform: template
    name: "Controller Polling"
    entity_category: diagnostic
    lambda: return id(mitm).get_controller_polling();

sensor:
  - platform: template
    name: "Desk Height"
    unit_of_measurement: "cm"
    accuracy_decimals: 1
    update_interval: 500ms
    lambda: |-
      float h = id(mitm).get_height();
      if (std::isnan(h)) return {};
      return h;

switch:
  - platform: template
    name: "Emulation Mode"
    id: emulation_mode
    optimistic: true
    restore_mode: RESTORE_DEFAULT_OFF
    turn_on_action:
      - lambda: id(mitm).set_emulation(true);
    turn_off_action:
      - lambda: id(mitm).set_emulation(false);

button:
  - platform: template
    name: "Desk Up (jog)"
    on_press: [lambda: 'id(mitm).inject(0x01, 300);']
  - platform: template
    name: "Desk Down (jog)"
    on_press: [lambda: 'id(mitm).inject(0x02, 300);']
  - platform: template
    name: "Desk Stop"
    on_press: [lambda: 'id(mitm).stop();']
  - platform: template
    name: "Desk Preset 1"
    on_press: [lambda: 'id(mitm).inject(0x04, 150);']
  - platform: template
    name: "Desk Preset 2"
    on_press: [lambda: 'id(mitm).inject(0x08, 150);']
  - platform: template
    name: "Desk Preset 3"
    on_press: [lambda: 'id(mitm).inject(0x10, 150);']
```

- [ ] **Step 5: Validate and compile**

Run: `esphome config desk-mitm.yaml && esphome compile desk-mitm.yaml`
Expected: `Configuration is valid!` then `Successfully compiled program.` Fix any API drift (this is the only layer where ESPHome version details can bite; the protocol logic is already test-proven).

- [ ] **Step 6: Run host tests once more (regression)**

Run: `c++ -std=c++17 -o build/test_protocol tests/test_protocol.cpp && ./build/test_protocol`
Expected: `all tests passed`

- [ ] **Step 7: Commit**

```bash
git add components desk-mitm.yaml && git commit -m "feat: desk_mitm ESPHome component and node config"
```

---

### Task 6: Bench rewiring (desk unplugged throughout)

**Files:** none — hardware.

- [ ] **Step 1: Cut lines 6 and 4** in the coupler. Lines 1, 2, 3, 5, 7, 8 stay bridged.

- [ ] **Step 2: Wire the new segments**

- Keypad-side pin 6 → shifter HV1 (already there from Phase 1 — verify it's the *keypad-side* segment after the cut)
- Desk-side pin 5 tap → shifter HV2 (already there — pin 5 is uncut, tap point unchanged)
- Shifter HV3 → desk-side pin 6; LV3 ← GPIO26
- Shifter HV4 → desk-side pin 4; LV4 ← GPIO27
- Keypad-side pin 4 → existing 4.7k/10k divider → GPIO34 (verify divider now hangs on the keypad-side segment)

- [ ] **Step 3: Meter checks before power-up**

Continuity: desk-side pin 6 must NOT reach keypad-side pin 6; same for pin 4. Divider: keypad-side pin 4 → 4.7k → GPIO34 node → 10k → GND.

- [ ] **Step 4: Power up, sanity**

Plug desk in. ESP boots (it still runs the sniffer or old firmware — fine). No smoke, 5 V present on pin 8, ESP joins WiFi.

---

### Task 7: Verification ladder 1 — echo build

**Files:** none — uses `desk-mitm.yaml` from Task 5.

- [ ] **Step 1: Flash** — `esphome run desk-mitm.yaml --device 192.168.40.65 --no-logs`. Expected: `OTA successful`.

- [ ] **Step 2: Keypad factory-function test** (Emulation Mode switch OFF = echo)

Wake keypad; display shows height; up/down move desk; a preset works end-to-end. Expected log lines: `controller polling started`, no `forwarded keypad frame` spam, no CRC warnings.
**This step is the moment of truth for the whole 5 V TX theory** — if the desk responds to keypad buttons, our ESP-transmitted frames are being accepted by the controller.

- [ ] **Step 3: Capture 2 minutes** — `esphome logs desk-mitm.yaml --device 192.168.40.65 2>&1 | tee captures/2026-08-08-phase2-echo.log` while using the keypad. Commit:

```bash
git add captures/ && git commit -m "data: phase 2 echo-mode verification capture"
```

---

### Task 8: Verification ladder 2 — emulation + kill-switches

**Files:** none.

- [ ] **Step 1: Flip "Emulation Mode" ON** (HA or web UI). Keypad must behave identically (buttons, display, presets).

- [ ] **Step 2: Height sensor check** — move desk with keypad; "Desk Height" in HA tracks within ~1 s.

- [ ] **Step 3: Kill-switch check** — hold Up on the keypad and, mid-move, unplug the keypad's RJ45. Desk must stop within ~500 ms (poll-timeout clears keys; controller stops on idle replies). Replug; everything recovers.

---

### Task 9: Verification ladder 3 — injection (keypad awake)

**Files:** none.

- [ ] **Step 1:** Keypad awake → press "Desk Preset 1" in HA. Desk moves to 121 cm.
- [ ] **Step 2:** "Desk Up (jog)" nudges ~1 cm; "Desk Down (jog)" nudges back.
- [ ] **Step 3:** Start a preset move from HA, then press "Desk Stop" mid-move. Record whether the preset move cancels (it stops manual jogs by design; preset-cancel is the open question). Note the result for the findings addendum in Task 10.

---

### Task 10: Verification ladder 4+5 — ESP wake + abuse pass, findings addendum

**Files:**
- Create: `docs/superpowers/specs/2026-08-08-phase2-findings.md`

- [ ] **Step 1: Cold wake** — let the keypad sleep (PIN 20 OFF), press "Desk Preset 2" in HA. Expected: log `controller asleep; raising PIN20 and deferring injection`, then `controller polling started`, desk moves. Note how long polling took to start after PIN 20 drive.
- [ ] **Step 2: UART-only wake observation** — in the captured logs from step 1, check whether any polling occurred *before* PIN 20 was driven (it should not have; record the definitive answer).
- [ ] **Step 3: Abuse pass** — reboot ESP mid-move (power cycle); OTA mid-move; press keypad Up while an HA injection is active (physical must win after the ≤300 ms injection window); HA preset while keypad is mid-manual-move.
- [ ] **Step 4: Write `docs/superpowers/specs/2026-08-08-phase2-findings.md`** — results of Tasks 7–10: echo/emulation parity, stop-vs-preset answer, wake timing, abuse-pass outcomes, any protocol surprises (new frame types hit the verbatim-forward path — grep logs for `forwarded keypad frame`).
- [ ] **Step 5: Commit**

```bash
git add docs captures && git commit -m "docs: phase 2 verification results and findings"
```

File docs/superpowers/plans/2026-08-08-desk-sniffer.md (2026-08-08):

# Phase 1 Passive Desk Sniffer Implementation Plan

> **For agentic workers:** REQUIRED SUB-SKILL: Use superpowers:subagent-driven-development (recommended) or superpowers:executing-plans to implement this plan task-by-task. Steps use checkbox (`- [ ]`) syntax for tracking.

**Goal:** A passive ESPHome tap that logs all desk↔keypad UART traffic and PIN 20 edges while the keypad runs in a factory-original circuit, producing captures that answer what the HS01B-1 keypad sends and how PIN 20 behaves.

**Architecture:** All 8 RJ45 lines straight through desk↔keypad; three lines branch to the ESP32 (two UART RX-only taps via a BSS138 level shifter, PIN 20 via resistor divider to an input-only GPIO). The node transmits nothing. Spec: `docs/superpowers/specs/2026-08-08-desk-sniffer-design.md`.

**Tech Stack:** ESPHome (installed, latest), generic `esp32dev` devkit, 2× female RJ45 breakouts, 4-ch BSS138 level shifter, 4.7k + 10k resistors.

**Verification model:** Hardware project — "tests" are `esphome config`/`compile` gates, multimeter checks before each connection, and observable behavior (keypad works, frames appear in logs). Each task ends verified before the next.

---

### Task 1: ESPHome sniffer config

**Files:**
- Create: `desk-sniffer.yaml`
- Uses: `secrets.yaml` (exists: `wifi_ssid`, `wifi_password`)

- [ ] **Step 1: Write `desk-sniffer.yaml`**

```yaml
esphome:
  name: desk-sniffer
  friendly_name: Flexispot Desk

esp32:
  board: esp32dev
  framework:
    type: esp-idf

logger:
  level: DEBUG

api:

ota:
  - platform: esphome

wifi:
  ssid: !secret wifi_ssid
  password: !secret wifi_password
  use_address: 192.168.40.65
  ap:
    ssid: "Desk-Sniffer Fallback"

captive_portal:

# Both buses are RX-only taps. The ESP transmits nothing in Phase 1.
uart:
  - id: uart_desk    # controller -> keypad line (RJ45 pin 6)
    rx_pin: GPIO16
    baud_rate: 9600
    debug:
      direction: RX
      dummy_receiver: true
      after:
        delimiter: [0x9D]
      sequence:
        - lambda: |-
            std::string hex;
            char buf[4];
            for (auto b : bytes) { sprintf(buf, "%02X:", b); hex += buf; }
            if (!hex.empty()) hex.pop_back();
            ESP_LOGD("DESK", "%s", hex.c_str());
  - id: uart_keypad  # keypad -> controller line (RJ45 pin 5)
    rx_pin: GPIO17
    baud_rate: 9600
    debug:
      direction: RX
      dummy_receiver: true
      after:
        delimiter: [0x9D]
      sequence:
        - lambda: |-
            std::string hex;
            char buf[4];
            for (auto b : bytes) { sprintf(buf, "%02X:", b); hex += buf; }
            if (!hex.empty()) hex.pop_back();
            ESP_LOGD("KEYPAD", "%s", hex.c_str());

binary_sensor:
  - platform: gpio
    pin:
      number: GPIO34
      mode:
        input: true
    name: "PIN 20"
    id: pin20
```

Notes for the implementer:
- `friendly_name: Flexispot Desk` matches what HA already shows. The old node's API key is lost, so HA will re-discover this as a fresh ESPHome device — delete the stale HA device entry and adopt the new one when prompted.
- `after: delimiter: [0x9D]` flushes a log line at each frame terminator; a partial tail also flushes on the default 100 ms timeout.
- GPIO34 is input-only and has no internal pulls — correct here, the divider defines the level.
- Binary sensor state changes are logged with timestamps by the logger automatically; no extra config needed.

- [ ] **Step 2: Validate the config**

Run: `esphome config desk-sniffer.yaml`
Expected: full rendered config printed, exit 0, no red errors. (`api:` with no key will auto-note a generated key — fine.)

- [ ] **Step 3: Compile**

Run: `esphome compile desk-sniffer.yaml`
Expected: ends with `Successfully compiled program` (first build downloads esp-idf toolchain, takes minutes).

- [ ] **Step 4: Commit**

```bash
git add desk-sniffer.yaml
git commit -m "feat: Phase 1 passive sniffer node (RX-only taps + PIN20 sense)"
```

---

### Task 2: Bench wiring (no ESP connected yet)

**Files:** none — hardware. Multimeter checks gate every connection.

- [ ] **Step 1: Straight-through coupling**

Wire all 8 lines of the two female RJ45 breakouts 1:1 (1→1 … 8→8). Plug desk cable into one jack, keypad into the other.

- [ ] **Step 2: Verify factory behavior through the coupler**

Power the desk. Expected: keypad display lights/shows height, up/down buttons move the desk. If not, stop and fix continuity (meter each pin 1→1 … 8→8) — failure here is crimps, not protocol.

- [ ] **Step 3: Shifter power rails**

Shifter HV ← RJ45 pin 8 (+5 V); shifter LV ← nothing yet (ESP 3V3 comes later); shifter GND ← RJ45 pin 7. Do not connect channel wires to the ESP yet.

- [ ] **Step 4: Signal branches**

- RJ45 pin 6 branch → shifter HV1
- RJ45 pin 5 branch → shifter HV2
- RJ45 pin 4 branch → 4.7k resistor → node "P20_TAP" → 10k resistor → GND (pin 7)

- [ ] **Step 5: Meter the low sides before any ESP connection**

Desk powered, keypad awake. Measure vs GND:
- P20_TAP: expect ≈ 2.8 V (4.1 V × 10/14.7) awake, ≈ 0 V asleep
- LV1/LV2 with LV rail unpowered: expect ≈ 0 V (channels are dead without LV ref — that's fine)

Any P20_TAP reading > 3.4 V: stop, recheck resistor order.

---

### Task 3: First flash and network verification (ESP on USB, RJ45 power lead disconnected)

**Files:** none — uses `desk-sniffer.yaml` from Task 1.

- [ ] **Step 1: Isolate desk power from ESP**

Disconnect the pin 8→VIN lead (or don't connect it yet). ESP on USB only. GND lead (pin 7→ESP GND) can be connected — shared ground is required and safe.

- [ ] **Step 2: Flash over USB**

Run: `esphome run desk-sniffer.yaml` and pick the serial port.
Expected: flash succeeds, boot log shows WiFi connected with IP `192.168.40.65`.

- [ ] **Step 3: Verify OTA log path**

Unplug USB, replug (still no RJ45 5 V). Run: `esphome logs desk-sniffer.yaml`
Expected: connects over the network, streams logs. From here on, USB is only needed for recovery.

---

### Task 4: Connect taps and go standalone

**Files:** none — hardware.

- [ ] **Step 1: Connect ESP with everything unpowered**

Desk unplugged, USB out. Connect: shifter LV ← ESP 3V3, LV1 → GPIO16, LV2 → GPIO17, P20_TAP → GPIO34, RJ45 pin 8 → VIN, pin 7 → ESP GND.

- [ ] **Step 2: Power up from the desk**

Plug in the desk. Expected: ESP boots (LED), joins WiFi, `esphome logs desk-sniffer.yaml` streams.

- [ ] **Step 3: Keypad still factory-functional**

Expected: display shows height, buttons move desk — identical to Task 2 Step 2. If the keypad broke, the taps are loading the bus: check shifter channel wiring (a swapped HV/LV would do this).

- [ ] **Step 4: Traffic smoke test**

Watch logs; wake the keypad and press up briefly. Expected: `[DESK]` and/or `[KEYPAD]` hex lines appear, `PIN 20` binary sensor flips. Frames should start `9B` and end `9D`. Garbage bytes → suspects: pins 5/6 swapped at the branch, or wrong baud (shouldn't be — 9600 is documented).

---

### Task 5: Capture session

**Files:**
- Create: `captures/2026-08-08-session1.log` (raw)
- Create: `captures/2026-08-08-session1.md` (annotated timeline)

- [ ] **Step 1: Record raw log**

Run: `mkdir -p captures && esphome logs desk-sniffer.yaml 2>&1 | tee captures/2026-08-08-session1.log`

- [ ] **Step 2: Scripted actions, ~5 s apart, noting wall-clock time of each**

1. Idle 60 s, keypad asleep
2. Wake keypad (touch/any button), then idle 10 s
3. Up — short tap; 4. Up — hold 2 s; 5. Down — short tap; 6. Down — hold 2 s
7. Preset 1; 8. Preset 2; 9. Preset 3 (let each move finish)
10. M button alone; 11. Program a preset (M then a preset key)
12. Let keypad time out to sleep, idle 30 s

Write each action + timestamp into `captures/2026-08-08-session1.md` as you go.

- [ ] **Step 3: Commit captures**

```bash
git add captures/
git commit -m "data: Phase 1 sniff session 1 (raw + annotated)"
```

---

### Task 6: Protocol analysis write-up

**Files:**
- Create: `docs/superpowers/specs/2026-08-08-phase1-findings.md`

- [ ] **Step 1: Decode the capture**

Cross-reference `captures/2026-08-08-session1.log` against the LoctekMotion command table (https://github.com/iMicknl/LoctekMotion_IoT — command frames `9b 06 02 <k1> <k2> <crc> 9d`, height frames from controller). Produce the findings doc answering, with quoted frames:
- (a) Which frames does the keypad emit per button? Do they match the documented `9b 06 02 …` set?
- (b) PIN 20 timeline: level at rest / edge relative to wake / behavior during presses and moves. Who drives it (does it rise before the first keypad frame or after a controller frame)?
- (c) Any undocumented frames (e.g. the `9B:05:02:00:A1:60:9D` heartbeat from issue #146 — which side sends it, when).
- (d) Consequences for Phase 2: what the MITM must forward/drive on PIN 20, and required forwarding latency (max observed inter-frame gap).

- [ ] **Step 2: Commit**

```bash
git add docs/superpowers/specs/2026-08-08-phase1-findings.md
git commit -m "docs: Phase 1 sniff findings"
```

Exit criterion (from spec): questions (a) and (b) answered from captures. Phase 2 design starts from the findings doc.

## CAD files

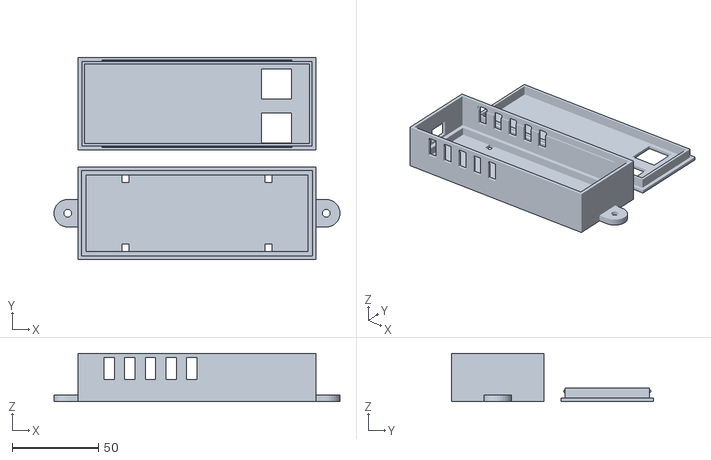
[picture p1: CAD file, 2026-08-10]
case/desk-case.stl
166.1 x 117.2 x 28.1

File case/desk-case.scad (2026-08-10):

// Desk MITM enclosure — parametric OpenSCAD
// Board: 132.5 x 48 perfboard, ESP32 USB out one end wall, two RJ45 jacks
// facing UP through the lid at the other end, solder pins protruding below.
//
// Coordinates: X = board length (USB end at x=0, RJ45 end at x=max),
//              Y = board width, Z = up. All openings are parametric — print,
//              test-fit, nudge the offending variable, reprint the one part.
//
// Render:  openscad -D part=\"base\" -o base.stl desk-case.scad
//          openscad -D part=\"lid\"  -o lid.stl  desk-case.scad
// Preview: open in OpenSCAD GUI, set `part` below to "base", "lid" or "both".

part = "both";  // "base" | "lid" | "both" (preview)

/* ---------- board ---------- */
board_l      = 132.5;  // perfboard length
board_w      = 48.0;   // perfboard width
board_th     = 1.6;    // perfboard thickness
pins_below   = 5.0;    // clearance under board for solder pins/wires
above_board  = 30.0;   // headroom above board top — must clear the tall RJ45 support PCB

/* ---------- case ---------- */
wall         = 2.0;    // wall thickness
floor_th     = 2.0;
lid_th       = 2.0;
clearance    = 0.8;    // gap around the board (FDM slop; increase if tight)
headroom     = 1.5;    // extra air above the tallest component
lip_h        = 6.0;    // lid skirt depth (longer = more flex for the snap)

/* ---------- lid attachment ---------- */
lid_mode     = "snap";  // "snap" (no fasteners) | "screw" (corner towers)
// snap tuning — reprint the lid and adjust if it's too loose/tight:
snap_bead_d  = 1.6;    // rounded catch bead diameter on the skirt
snap_depth   = 0.9;    // how deep the groove cuts into the base wall
snap_gap     = 0.25;   // skirt-to-wall running clearance (matches skirt offset)

// Segmented skirt: the lip only exists at the USB end and the two long-wall
// centers (which carry the snaps). The RJ45 end has NO skirt — the jacks
// through their lid holes locate that end, so nothing crowds them there.
skirt_end_len = 18.0;  // skirt depth region at the USB end (x from 0)
skirt_center  = 46.0;  // center segment length on the long walls

/* ---------- USB opening (end wall at x=0) ---------- */
usb_w        = 13.0;   // opening width
usb_h        = 9.0;    // opening height
usb_y_off    = 0.0;    // sideways offset from board centerline ("fairly centered, but not 100%")
usb_z        = 0.0;    // opening bottom relative to board TOP surface (USB sits just above board)

/* ---------- RJ45 lid openings (jacks face up, near x=max end) ---------- */
// Positions are centers. x measured from the INNER face of the RJ45-end wall
// (i.e. from the far edge of the board), y from the board centerline.
rj45_hole_w  = 17.5;   // hole size along X (jack depth + slop)
rj45_hole_d  = 17.5;   // hole size along Y (jack width + slop)
rj45_a_x     = 12.0;   // jack A center, distance back from board far edge
rj45_a_y     = -11.5;  // jack A center, offset from centerline (negative = one side)
rj45_b_x     = 12.0;   // jack B center
rj45_b_y     = 11.5;   // jack B center

/* ---------- board mounting ---------- */
ledge_w      = 2.5;    // perimeter shelf the board rests on
screw_d      = 2.8;    // pilot hole for M3 self-tappers
screw_head_d = 6.2;    // lid countersink
vent_slots   = true;   // side vents over the ESP32 half
zip_slots    = true;   // zip-tie slots in the base for under-desk mounting

/* ---------- mounting ears (screw to desk underside, floor against the desk) ---------- */
ears         = true;
ear_len      = 13.0;   // how far each ear sticks out past the end wall
ear_w        = 16.0;   // ear width
ear_th       = 4.0;    // ear thickness (= floor plane up)
ear_hole_d   = 4.5;    // wood screw clearance
ear_y_off    = 0.0;    // sideways offset from case centerline (dodge desk frame members)

/* ---------- derived ---------- */
in_l  = board_l + 2*clearance;
in_w  = board_w + 2*clearance;
in_h  = pins_below + board_th + above_board + headroom;
out_l = in_l + 2*wall;
out_w = in_w + 2*wall;
base_h = floor_th + in_h - lip_h;          // lid skirt completes the height
board_z = floor_th + pins_below;           // board underside
board_top = board_z + board_th;

$fn = 32;
eps = 0.01;

// Lid screws live in EXTERNAL corner towers so nothing intrudes into the
// cavity — the board fills the interior wall-to-wall and must stay untouched.
tower_d = 9.0;
corner_pts = [[0, 0], [out_l, 0], [0, out_w], [out_l, out_w]];

module corner_towers() {
  for (p = corner_pts)
    translate([p[0], p[1], 0]) difference() {
      cylinder(d = tower_d, h = base_h);
      translate([0, 0, base_h - 12]) cylinder(d = screw_d, h = 12 + eps);
    }
}

// Snap geometry, symmetric about both centerlines so the lid's 180° flip
// still lines the beads up with the grooves. bead center height (installed):
snap_z    = base_h - lip_h + 2;
snap_len  = skirt_center - 10;          // sits within the center skirt segment
snap_x0   = out_l/2 - snap_len/2;

module base_snap_grooves() {  // cut into the two long walls' inner faces
  for (yy = [[wall - snap_depth, wall + eps],
             [out_w - wall - eps, out_w - wall + snap_depth]])
    translate([snap_x0, yy[0], snap_z - snap_bead_d/2 - 0.4])
      cube([snap_len, yy[1] - yy[0], snap_bead_d + 0.8]);
}

module lid_snap_beads() {  // rounded beads on the skirt outer faces (lid coords)
  z = lid_th + lip_h - 2;  // maps to snap_z once installed
  for (y = [wall + snap_gap, out_w - wall - snap_gap])
    translate([snap_x0, y, z]) rotate([0, 90, 0])
      cylinder(d = snap_bead_d, h = snap_len);
}

module ear(dir) {  // dir: -1 = x=0 end, +1 = x=out_l end
  hole_x = (dir < 0) ? -ear_len + ear_w/2 - 1 : out_l + ear_len - ear_w/2 + 1;
  anchor_x = (dir < 0) ? 0.5 : out_l - 0.5;
  difference() {
    hull() {
      translate([hole_x, out_w/2 + ear_y_off, 0]) cylinder(d = ear_w, h = ear_th);
      translate([anchor_x - 0.5, out_w/2 + ear_y_off - ear_w/2, 0])
        cube([1, ear_w, ear_th]);
    }
    translate([hole_x, out_w/2 + ear_y_off, -eps]) cylinder(d = ear_hole_d, h = ear_th + 2*eps);
  }
}

module base() {
  if (ears) {
    ear(-1);
    ear(1);
  }
  difference() {
    union() {
      // shell
      difference() {
        cube([out_l, out_w, base_h]);
        translate([wall, wall, floor_th]) cube([in_l, in_w, base_h]);
      }
      // board ledge (overlaps floor and walls slightly for clean manifold union)
      difference() {
        translate([wall - 0.1, wall - 0.1, floor_th - 0.1])
          cube([in_l + 0.2, in_w + 0.2, pins_below + 0.1]);
        translate([wall + ledge_w, wall + ledge_w, floor_th - 0.2])
          cube([in_l - 2*ledge_w, in_w - 2*ledge_w, pins_below + 0.4]);
      }
      if (lid_mode == "screw") corner_towers();
    }
    if (lid_mode == "snap") base_snap_grooves();
    // USB opening in the x=0 end wall
    translate([-eps,
               out_w/2 + usb_y_off - usb_w/2,
               board_top + usb_z])
      cube([wall + 2*eps, usb_w, usb_h]);
    // vents over the ESP32 half, both long sides
    if (vent_slots)
      for (y = [-eps, out_w - wall - eps])
        for (x = [15 : 12 : board_l/2])
          translate([x, y, floor_th + pins_below + 6])
            cube([6, wall + 2*eps, base_h - (floor_th + pins_below + 6) - 2.5]);
    // zip-tie slots through the floor near each end
    if (zip_slots)
      for (x = [out_l*0.2, out_l*0.8])
        for (y = [wall + 2, out_w - wall - 2 - 5])
          translate([x - 2, y, -eps]) cube([4, 5, floor_th + 2*eps]);
  }
}
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

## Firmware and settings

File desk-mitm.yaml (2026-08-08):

substitutions:
  # Calibrated 2026-08-08: physical travel limits read from the display.
  min_height: "71.0"
  max_height: "121.0"

esphome:
  name: desk-sniffer
  friendly_name: Flexispot Desk
  on_boot:
    priority: -100  # after all components are up
    then:
      - lambda: id(mitm).request_height();

esp32:
  board: esp32dev
  framework:
    type: esp-idf

external_components:
  - source:
      type: local
      path: components

logger:
  level: DEBUG

api:

ota:
  - platform: esphome

wifi:
  ssid: !secret wifi_ssid
  password: !secret wifi_password
  use_address: 192.168.40.65
  ap:
    ssid: "Desk-Sniffer Fallback"

captive_portal:

# Local REST API (http://192.168.40.65) — used to drive verification without HA.
web_server:
  version: 3

uart:
  - id: uart_desk    # RX: controller TX tap (RJ45 pin 5, desk side); TX: controller RX (pin 6, desk side)
    rx_pin: GPIO17
    tx_pin: GPIO23
    baud_rate: 9600
  - id: uart_keypad  # RX only: keypad TX (RJ45 pin 6, keypad side)
    rx_pin: GPIO16
    baud_rate: 9600

desk_mitm:
  id: mitm
  desk_uart: uart_desk
  keypad_uart: uart_keypad
  pin20_sense_pin:
    number: GPIO21
    allow_other_uses: true
    mode:
      input: true
  pin20_drive_pin:
    number: GPIO22
    mode:
      output: true
  min_height: ${min_height}
  max_height: ${max_height}

binary_sensor:
  - platform: gpio
    pin:
      number: GPIO21
      allow_other_uses: true
      mode:
        input: true
    name: "Keypad Active"
    id: pin20
    entity_category: diagnostic
    icon: mdi:gesture-tap-button
  - platform: template
    name: "Controller Awake"
    entity_category: diagnostic
    disabled_by_default: true
    icon: mdi:chip
    lambda: return id(mitm).get_controller_polling();

sensor:
  - platform: template
    name: "Height"
    unit_of_measurement: "cm"
    accuracy_decimals: 1
    state_class: measurement
    icon: mdi:arrow-expand-vertical
    update_interval: 500ms
    lambda: |-
      float h = id(mitm).get_height();
      if (std::isnan(h)) return {};
      return h;
    filters:
      - delta: 0.01  # publish only on actual change; the lambda polls at 500ms regardless

cover:
  - platform: desk_mitm
    name: ""  # adopts the device name -> shows as "Flexispot Desk"
    icon: mdi:desk

number:
  - platform: desk_mitm
    name: "Target Height"
    unit_of_measurement: "cm"
    icon: mdi:human-male-height
    mode: box
    min_value: ${min_height}
    max_value: ${max_height}
    step: 0.1

switch:
  - platform: template
    name: "Emulation Mode"
    id: emulation_mode
    entity_category: config
    icon: mdi:robot
    optimistic: true
    restore_mode: RESTORE_DEFAULT_OFF
    turn_on_action:
      - lambda: id(mitm).set_emulation(true);
    turn_off_action:
      - lambda: id(mitm).set_emulation(false);

button:
  - platform: template
    name: "Nudge Up"
    icon: mdi:arrow-up-bold
    on_press: [lambda: 'id(mitm).inject(0x01, 300);']
  - platform: template
    name: "Nudge Down"
    icon: mdi:arrow-down-bold
    on_press: [lambda: 'id(mitm).inject(0x02, 300);']
  - platform: template
    name: "Stop"
    icon: mdi:stop-circle-outline
    on_press: [lambda: 'id(mitm).stop();']
  - platform: template
    name: "Preset 1"
    icon: mdi:numeric-1-box
    on_press: [lambda: 'id(mitm).inject(0x04, 150);']
  - platform: template
    name: "Preset 2"
    icon: mdi:numeric-2-box
    on_press: [lambda: 'id(mitm).inject(0x08, 150);']
  - platform: template
    name: "Preset 3"
    icon: mdi:numeric-3-box
    on_press: [lambda: 'id(mitm).inject(0x10, 150);']
  - platform: template
    name: "Refresh Height"
    entity_category: diagnostic
    icon: mdi:refresh
    on_press: [lambda: 'id(mitm).request_height();']

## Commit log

2026-08-08 Record measured line voltages; require 4.7k/10k dividers on all taps
2026-08-08 Use BSS138 level shifter for UART taps; keep divider on PIN 20
2026-08-08 docs: Phase 1 sniff findings — poll/response protocol, button map, PIN20 semantics
2026-08-08 feat: desk_mitm frame parser with capture-derived tests
2026-08-08 docs: README with wiring diagrams for publication
2026-08-08 fix: take watchdog timestamp after UART drain to avoid unsigned-time underflow
    The loop captured now=millis() before draining UARTs, but frame handlers
    stamp last_poll_ms_ with a fresh millis() during the drain, so the
    watchdog's (now - last_poll_ms_) underflowed and fired a false poll
    timeout every cycle, flapping polling state ~10x/second.
2026-08-08 feat: bounded retry for boot height fetch; manual Refresh Height button
2026-08-08 feat: Stop cancels in-flight preset via brief key tap; bounded boot height retry; Refresh Height button
    Stop semantics verified on hardware: idle replies never cancel a
    controller-autonomous move, but any brief up/down key does. Stop now
    taps 'up' for ~2 polls only when height changed within 500 ms.
2026-08-08 test: MoveController abort/stall/timeout/tap-limit/blind-start paths
2026-08-08 feat: calibrated desk travel range 71.0-121.0 cm
2026-08-08 docs: Phase 3 findings (0.1cm accuracy, live override) and README updates
2026-08-08 feat: move TX/PIN20 pins to GPIO15/GPIO2/GPIO4 (soldering-friendly layout)
2026-08-08 feat: final pin map GPIO23/22/21 — all ESP connections on one header row
2026-08-09 feat: parametric OpenSCAD enclosure (base + lid, RJ45 through lid, USB end wall)
    [desk-case.scad]
2026-08-09 feat: end-mounted screw ears for under-desk mounting
    [desk-case.scad]
2026-08-09 fix: move lid screws to external corner towers - internal posts clashed with the board
    [desk-case.scad]
2026-08-09 feat: snap-fit lid (default); screw mode retained via lid_mode toggle
    Skirt gets rounded catch beads on the long sides that click into grooves
    in the base walls — symmetric so the flip lines up, pries open by hand.
    [desk-case.scad]
2026-08-10 fix: segmented skirt (USB end + snap centers only) and taller box for RJ45 clearance
    RJ45 end has no skirt — jacks locate it through the lid holes, so a jack
    near the wall no longer collides with the lip. above_board 24->30 to clear
    the tall RJ45 support PCB.
    [desk-case.scad, desk-case.stl]
